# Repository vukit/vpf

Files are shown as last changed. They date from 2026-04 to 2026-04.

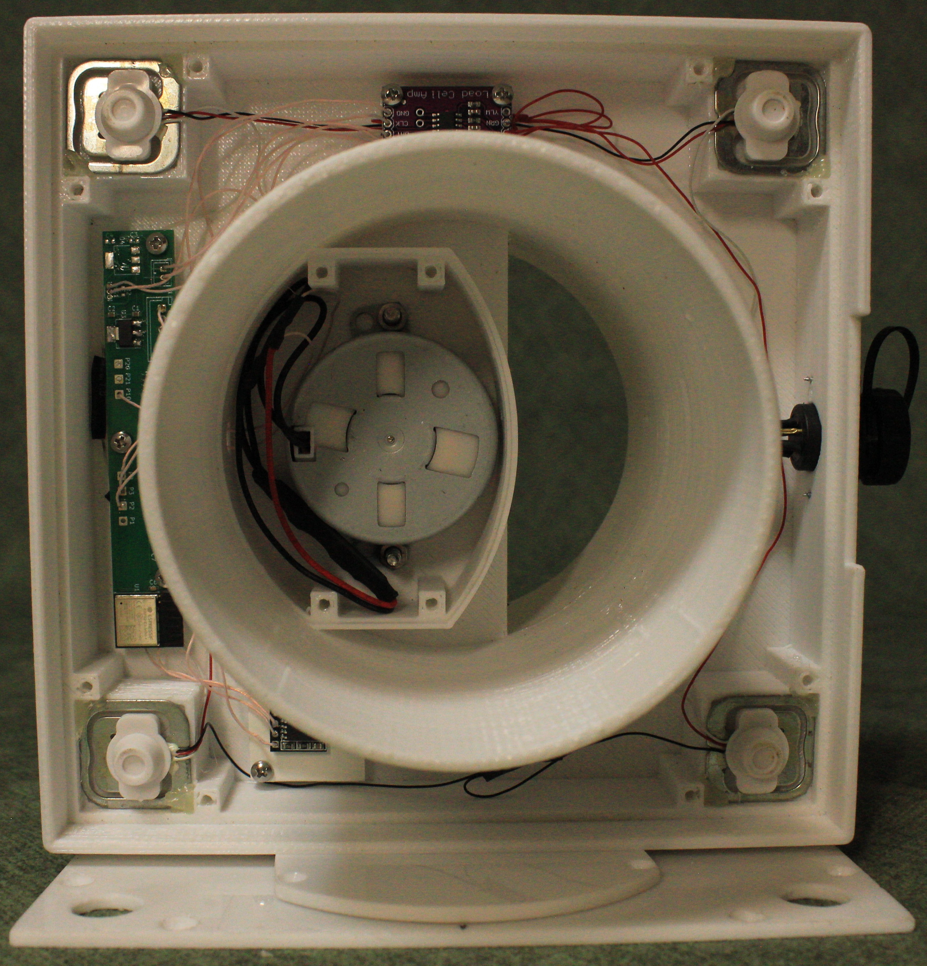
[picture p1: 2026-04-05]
photos/photo_1.jpg

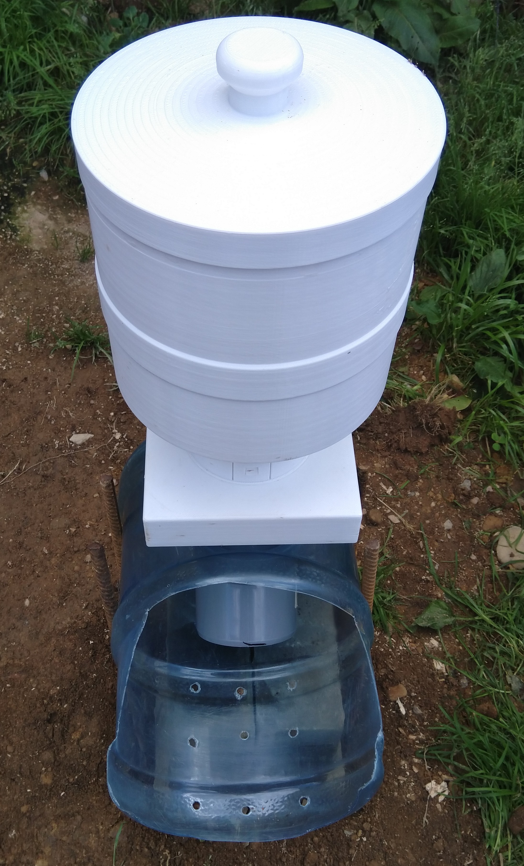
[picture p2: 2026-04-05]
photos/photo_2.jpg

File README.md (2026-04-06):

# Уличная кормушка для собак крупных пород

Надежная автоматизированная система кормления, спроектированная специально для крупных пород собак и эксплуатации в открытых вольерах. Проект успешно прошел проверку реальными условиями (снег, дождь, жара) и находится в эксплуатации с 2024 года.

## Ключевые особенности

*   **Компактный механизм:** Вместо громоздкого шнека использован оригинальный узел с пропеллером, что позволило существенно уменьшить габариты корпуса без потери производительности.
*   **Всепогодность:** Кормушка предназначена для установки на открытых площадках. Не требует навеса, дополнительной защиты или регулярной чистки механизма.
*   **Безопасность (5В):** Устройство питается от напряжения 5 вольт. Это гарантирует полную электрическую безопасность для питомца даже в случае повреждения кабеля.
*   **Автономность и объем:** Резервуар вмещает до 3.5 кг корма, чего достаточно для обеспечения собаки едой в течение 7 дней.
*   **Умная логика выдачи:** При временном отключении питания устройство автоматически «догоняет» график, выдавая пропущенные порции сразу после возобновления работы.

## Технические характеристики

*   **Точность дозирования:** ±20 грамм (порции задаются в граммах).
*   **График кормления:** До 3-х сессий в сутки в заданное время.
*   **Управление:** Мобильное приложение (связь через BLE).
*   **Функции приложения:** 
    *   Настройка расписания.
    *   Выдача порции вне очереди по команде.
    *   Обновление прошивки (OTA firmware update).

## Аппаратная часть
* **Микроконтроллер:** ESP32-C3.
* **Двигатель:** Bringsmart JS-50B(S) BLDC, DC 5V, CW/CCW, 2rpm, 10kgf/cm².
* **RTC:** Модуль DS3231 I2C.
* **Измерение веса:** TZT HX711 весовой модуль, 4 датчика FGHGF 34X34mm 5kg.
* **Питание:** 5В.

## Программное обеспечение
* **Язык:** firmware - C (ESP-IDF, FreeRTOS), приложение - Java (Android Studio).

## Опыт эксплуатации
Кормушка работает на открытом воздухе более 2-х лет, не требуя специального укрытия или частого технического обслуживания. Конструкция доказала свою устойчивость к обледенению и забиванию механизмов.

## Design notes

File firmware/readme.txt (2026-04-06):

Для успешной сборки проекта необходимо клонировать репозиторий https://github.com/UncleRus/esp-idf-lib.git в его корневую директорию

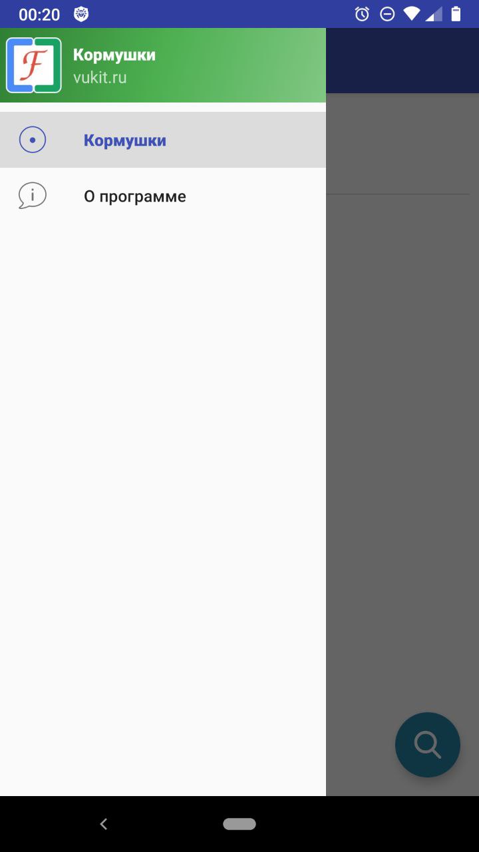
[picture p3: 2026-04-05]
screenshots/main_menu.jpg

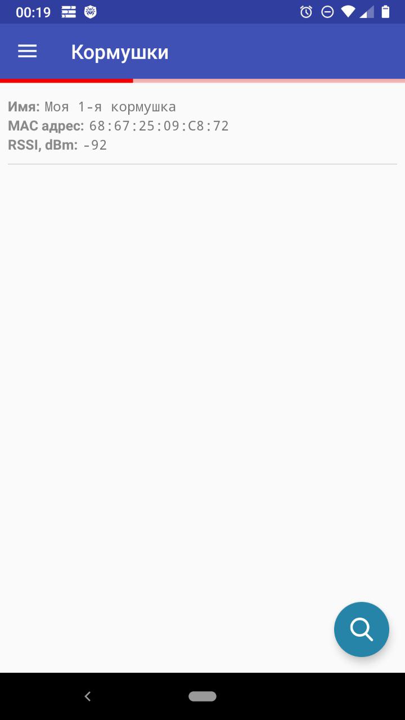
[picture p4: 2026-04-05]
screenshots/search_vpf.jpg

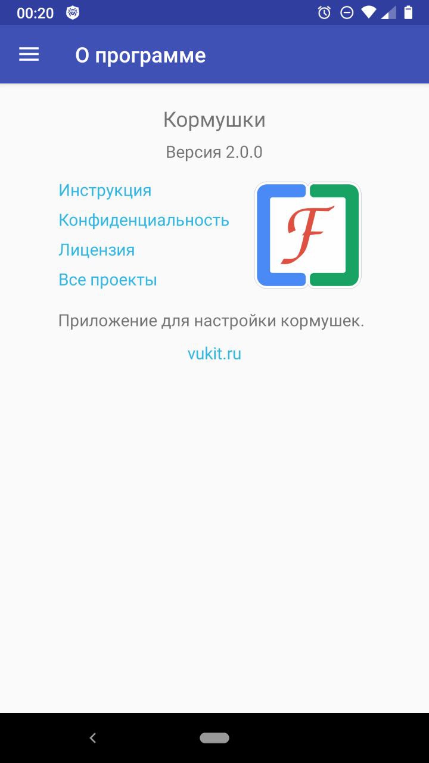
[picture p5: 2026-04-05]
screenshots/about.jpg

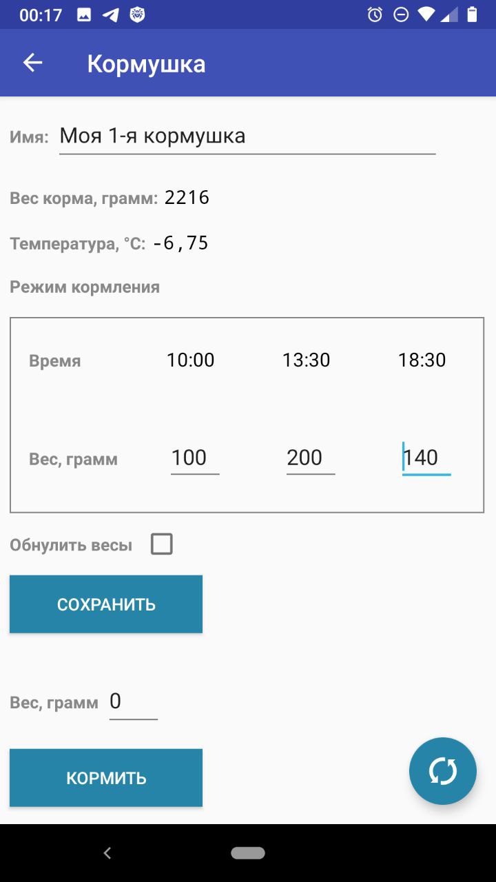
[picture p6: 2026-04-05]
screenshots/vpf_settings.jpg

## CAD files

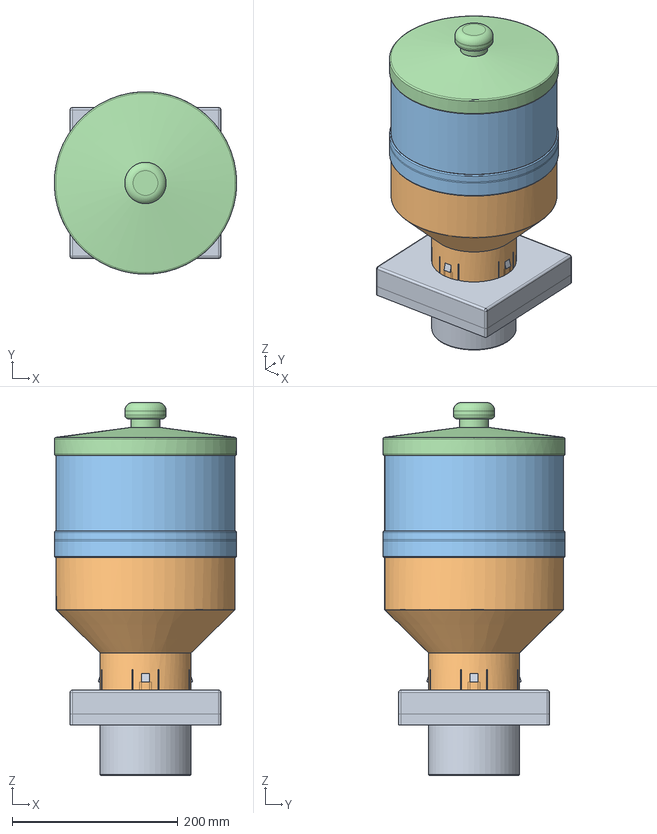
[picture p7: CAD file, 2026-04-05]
freecad/vpf_assembled.FCStd
220.0 x 219.9 x 450.0 mm
vpf_main_v2_001
vpf_tank_v2_001
vpf_ring_v2_001
vpf_cap_v2_001

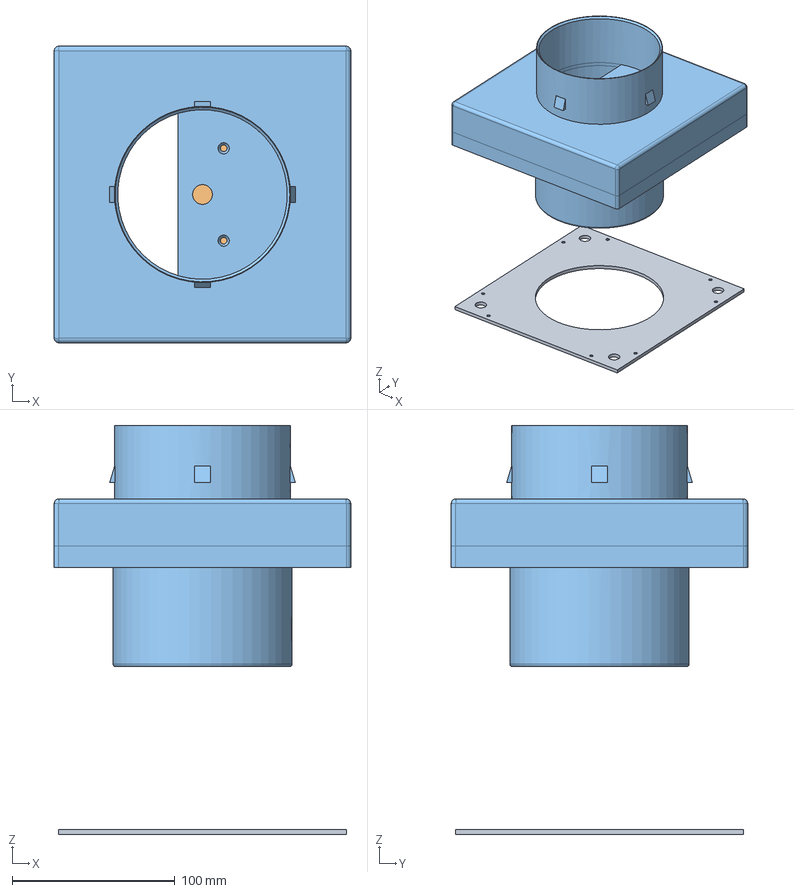
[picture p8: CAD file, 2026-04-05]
freecad/vpf_main.FCStd
182.0 x 182.0 x 251.0 mm
крышка
моторная_крышка
корпус

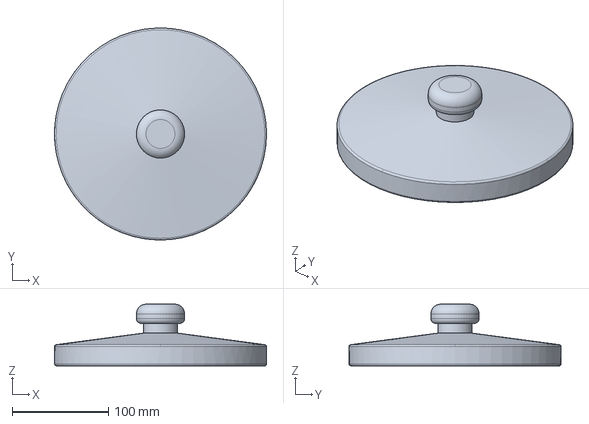
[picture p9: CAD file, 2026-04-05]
freecad/vpf_cap.FCStd
220.0 x 220.0 x 64.0 mm

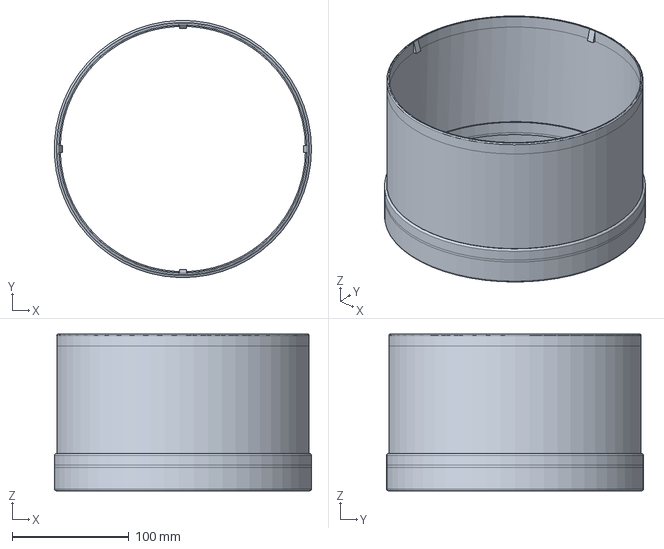
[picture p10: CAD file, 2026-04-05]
freecad/vpf_ring.FCStd
219.8 x 219.9 x 134.0 mm

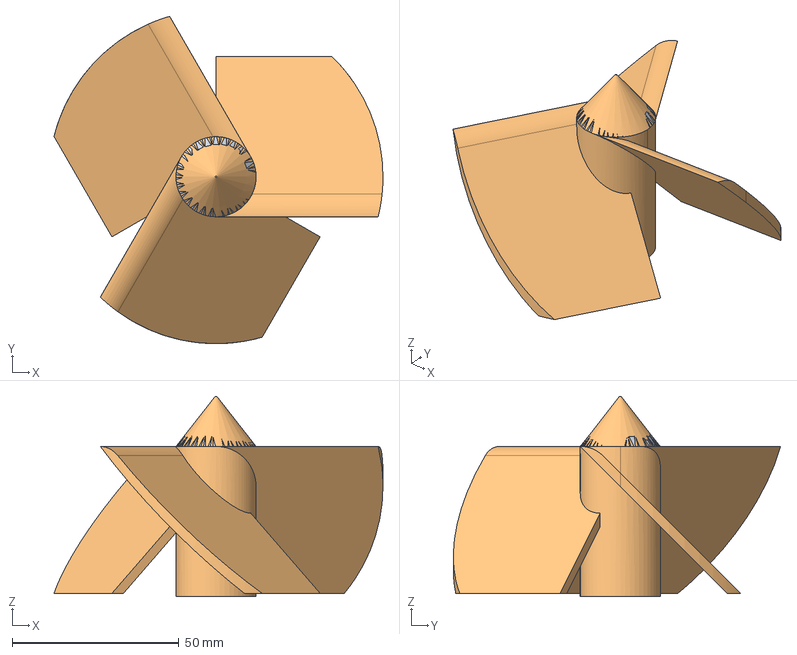
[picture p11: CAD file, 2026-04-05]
freecad/vpf_feeder.FCStd
98.5 x 98.0 x 60.0 mm
крышка
поддадчик

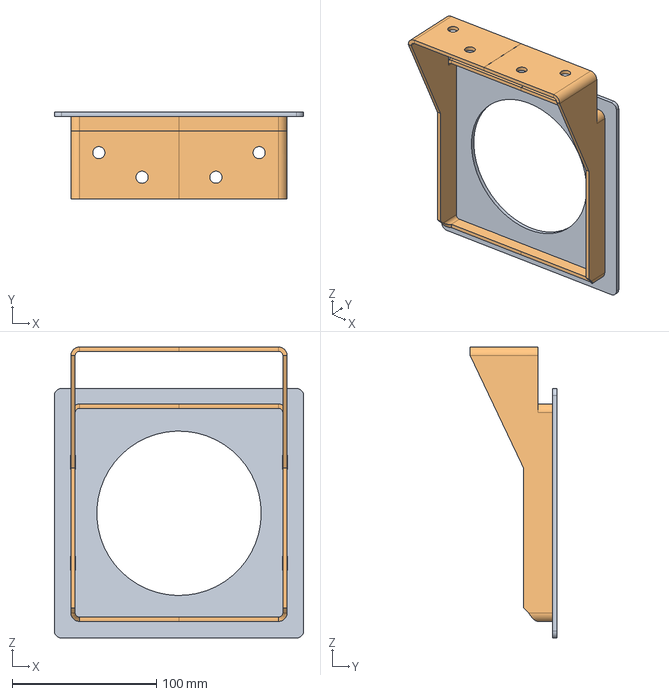
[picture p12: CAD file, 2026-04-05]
freecad/vpf_holder.FCStd
173.0 x 60.1 x 201.8 mm
верх
низ_развёртка

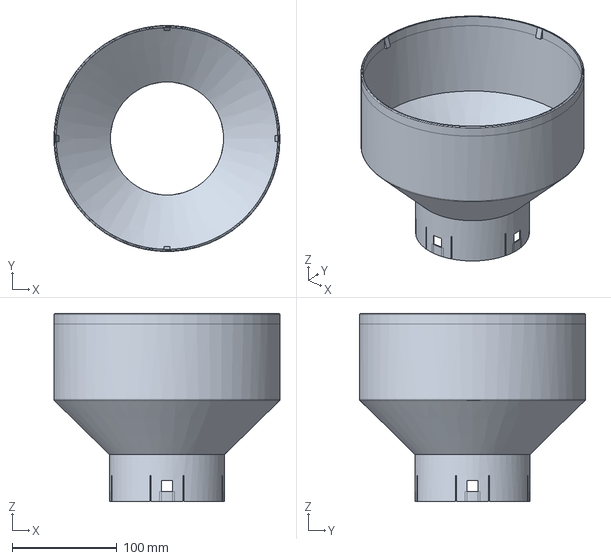
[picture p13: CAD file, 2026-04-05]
freecad/vpf_tank.FCStd
216.0 x 215.9 x 179.9 mm

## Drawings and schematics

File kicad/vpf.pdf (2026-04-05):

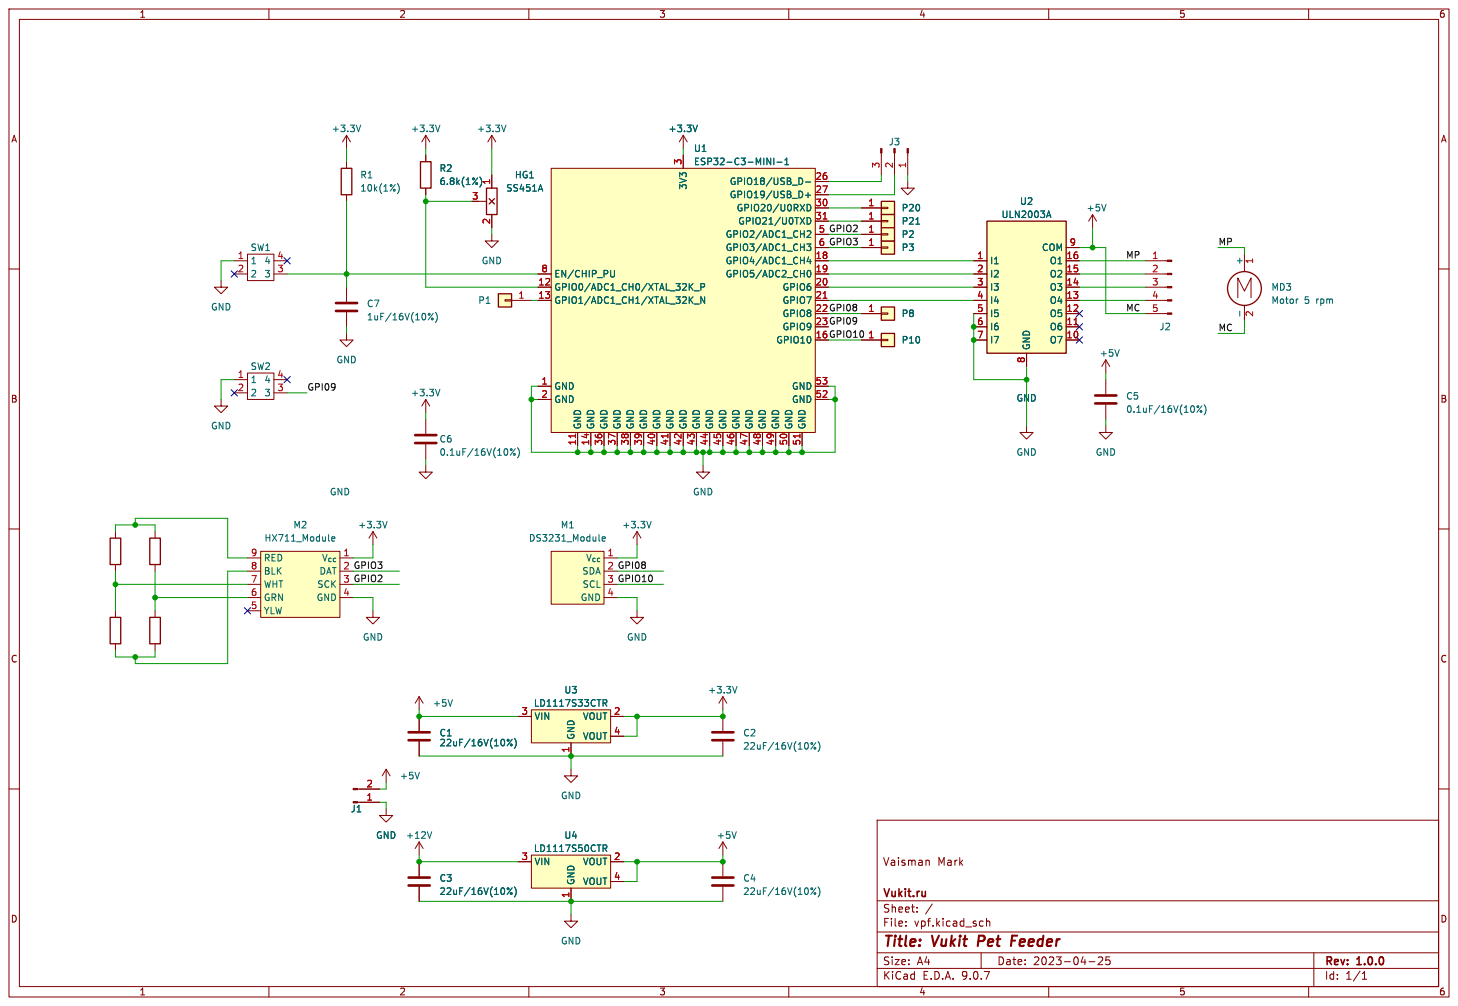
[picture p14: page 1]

3 GND 42 GND 43 GND 44 GND 45 GND 46 GND 47 GND 48 GND 49 GND 50 GND 51 GPIO18/USB_D- 26 GPIO19/USB_D+ 27 GPIO20/U0RXD 30 GPIO21/U0TXD 31 GPIO2/ADC1_CH2 5 GPIO3/ADC1_CH3 6 GPIO4/ADC1_CH4 18 GPIO5/ADC2_CH0 19 GPIO6 20 GPIO7 21 GPIO8 22 GPIO9 23 GPIO10 16 GND 53 GND 52 +3.3V

3 GND 42 GND 43 GND 44 GND 45 GND 46 GND 47 GND 48 GND 49 GND 50 GND 51 GPIO18/USB_D- 26 GPIO19/USB_D+ 27 GPIO20/U0RXD 30 GPIO21/U0TXD 31 GPIO2/ADC1_CH2 5 GPIO3/ADC1_CH3 6 GPIO4/ADC1_CH4 18 GPIO5/ADC2_CH0 19 GPIO6 20 GPIO7 21 GPIO8 22 GPIO9 23 GPIO10 16 GND 53 GND 52 U1ESP32-C3-MINI-1 GND MP MC GPIO2 GPIO3 GPIO2 MP GPIO10 GPI08 GPIO3 GPI09 GPI08 GPIO10 MC GPI09 U1ESP32-C3-MINI-1 EN/CHIP_PU 8 GPIO0/ADC1_CH0/XTAL_32K_P 12 GPIO1/ADC1_CH1/XTAL_32K_N 13 GND 1 GND 2 GND 11 GND 14 GND 36 GND 37 GND 38 GND 39 GND 40 GND 41 3V3

1 2 HG1 SS451A RED 9 BLK 8 WHT 7 GRN 6 YLW 5 V_{cc}1 DAT 2 SCK 3 GND 4 M2 HX711_Module

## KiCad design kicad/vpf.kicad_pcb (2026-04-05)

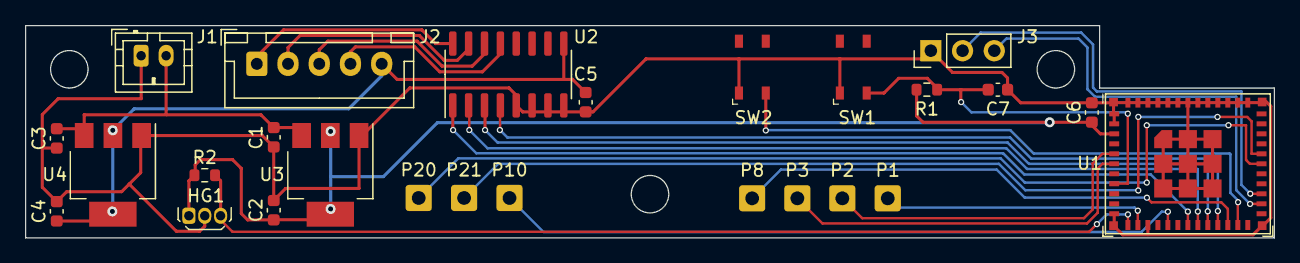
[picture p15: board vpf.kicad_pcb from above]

Board: 2 copper layers, 100.0 x 17.0 mm, 26 parts (0 on the bottom side), 24 nets.

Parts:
C1, C2, C3, C4: 22uF/16V(10%); C_0603_1608Metric
C5, C6: 0.1uF/16V(10%); C_0603_1608Metric
C7: 1uF/16V(10%); C_0603_1608Metric
HG1: SS451A; TO-92Flat
J1: Conn_01x02_Pin; JST_PH_B2B-PH-K_1x02_P2.00mm_Vertical
J2: Conn_01x05_Pin; JST_XH_B5B-XH-A_1x05_P2.50mm_Vertical
J3: Conn_01x03_Pin; PinHeader_1x03_P2.54mm_Vertical
P1, P2, P3, P8, P10, P20, P21: Conn_01x01; SolderWire-0.5sqmm_1x01_D0.9mm_OD2.1mm
R1: 10k(1%); R_0603_1608Metric
R2: 6.8k(1%); R_0603_1608Metric
SW1, SW2: PTS810SJM250SMTRLFS; SW_PUSH_4
U1: ESP32-C3-MINI-1
U2: ULN2003A; SOIC-16_3.9x9.9mm_P1.27mm
U3: LD1117S33CTR; SOT-223
U4: LD1117S50CTR; SOT-223

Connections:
+3.3V: C2.1, C6.1, HG1.1 (U1), R1.1, R2.1, U1.3 (3V3), U3.2 (VOUT), U3.4 (VOUT)
+5V: C4.1, C5.1, J2.5, U2.9 (COM), U4.2 (VOUT), U4.4 (VOUT)
+12V: C1.1, C3.1, J1.2, U3.3 (VIN), U4.3 (VIN)
/GPI09: SW2.3, U1.23 (GPIO9)
GND: C1.2, C2.2, C3.2, C4.2, C5.2, C6.2, C7.2, HG1.2 (U2), J1.1, J3.1, SW1.1, SW2.1, U1.1 (GND), U1.2 (GND), U1.11 (GND), U1.14 (GND), U1.36 (GND), U1.37 (GND), U1.38 (GND), U1.39 (GND), U1.40 (GND), U1.41 (GND), U1.42 (GND), U1.43 (GND), U1.44 (GND), U1.45 (GND), U1.46 (GND), U1.47 (GND), U1.48 (GND), U1.49 (GND), U1.50 (GND), U1.51 (GND), U1.52 (GND), U1.53 (GND), U2.5 (I5), U2.6 (I6), U2.7 (I7), U2.8 (GND), U3.1 (GND), U4.1 (GND)
unnamed: HG1.3 (UH1), R2.2, U1.12 (GPIO0/ADC1_CH0/XTAL_32K_P)
unnamed: J2.1, U2.16 (O1)
unnamed: J2.2, U2.15 (O2)
unnamed: J2.3, U2.14 (O3)
unnamed: J2.4, U2.13 (O4)
unnamed: J3.2, U1.27 (GPIO19/USB_D+)
unnamed: J3.3, U1.26 (GPIO18/USB_D-)
unnamed: P1.1, U1.13 (GPIO1/ADC1_CH1/XTAL_32K_N)
unnamed: P2.1, U1.5 (GPIO2/ADC1_CH2)
unnamed: P3.1, U1.6 (GPIO3/ADC1_CH3)
unnamed: P8.1, U1.22 (GPIO8)
unnamed: P10.1, U1.16 (GPIO10)
unnamed: P20.1, U1.30 (GPIO20/U0RXD)
unnamed: P21.1, U1.31 (GPIO21/U0TXD)
unnamed: C7.1, R1.2, SW1.3, U1.8 (EN/CHIP_PU)
unnamed: U1.18 (GPIO4/ADC1_CH4), U2.1 (I1)
unnamed: U1.19 (GPIO5/ADC2_CH0), U2.2 (I2)
unnamed: U1.20 (GPIO6), U2.3 (I3)
unnamed: U1.21 (GPIO7), U2.4 (I4)

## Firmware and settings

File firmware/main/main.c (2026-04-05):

#include "sdkconfig.h"
#include "freertos/FreeRTOS.h"
#include "nvs_flash.h"
#include "esp_log.h"
#include "esp_ota_ops.h"
#include "main.h"
#include "i2cdev.h"
#include "ble/server.h"
#include "motor/motor.h"
#include "state/state.h"
#include "scales/scales.h"
#include "clock/clock.h"
#include "command/command.h"
#include "worker/worker.h"

#define MAIN_LOG_TAG "MAIN"

bool run_diagnostics()
{
    // do some diagnostics
    return true;
}

void app_main(void)
{
    esp_err_t err;

    esp_reset_reason_t reason = esp_reset_reason();
    ESP_LOGI(MAIN_LOG_TAG, "Reset Reason : %X", reason);

    // check which partition is running
    const esp_partition_t *partition = esp_ota_get_running_partition();
    switch (partition->address)
    {
    case 0x00010000:
        ESP_LOGI(MAIN_LOG_TAG, "Running partition: factory");
        break;
    case 0x00110000:
        ESP_LOGI(MAIN_LOG_TAG, "Running partition: ota_0");
        break;
    case 0x00210000:
        ESP_LOGI(MAIN_LOG_TAG, "Running partition: ota_1");
        break;

    default:
        ESP_LOGE(MAIN_LOG_TAG, "Running partition: unknown");
        break;
    }

    // check if an OTA has been done, if so run diagnostics
    esp_ota_img_states_t ota_state;
    if (esp_ota_get_state_partition(partition, &ota_state) == ESP_OK)
    {
        if (ota_state == ESP_OTA_IMG_PENDING_VERIFY)
        {
            ESP_LOGI(MAIN_LOG_TAG, "An OTA update has been detected.");
            if (run_diagnostics())
            {
                ESP_LOGI(MAIN_LOG_TAG, "Diagnostics completed successfully! Continuing execution.");
                esp_ota_mark_app_valid_cancel_rollback();
            }
            else
            {
                ESP_LOGE(MAIN_LOG_TAG, "Diagnostics failed! Start rollback to the previous version.");
                esp_ota_mark_app_invalid_rollback_and_reboot();
            }
        }
    }

    // Initialize NVS
    err = nvs_flash_init();
    if (err == ESP_ERR_NVS_NO_FREE_PAGES || err == ESP_ERR_NVS_NEW_VERSION_FOUND)
    {
        ESP_ERROR_CHECK(nvs_flash_erase());
        err = nvs_flash_init();
    }
    ESP_ERROR_CHECK(err);

    // Initialize I2C
    err = i2cdev_init();
    if (err != ESP_OK)
    {
        ESP_LOGE(MAIN_LOG_TAG, "i2cdev_init(): %d (%s)\n", err, esp_err_to_name(err));
    }

    state_init();

    motor_init();

    scales_init();

    clock_init();

    ble_init();

    command_init();

    worker_run();
}

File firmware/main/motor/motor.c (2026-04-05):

#include <stdio.h>
#include "sdkconfig.h"
#include "freertos/FreeRTOS.h"
#include "driver/gpio.h"
#include "esp_log.h"
#include "motor.h"

#define MOTOR_LOG_TAG "MOTOR"

void motor_init()
{
    ESP_LOGI(MOTOR_LOG_TAG, "Motor initialization.");
    gpio_reset_pin(CONFIG_MOTOR_DRIVER_PORT);
    gpio_pulldown_en(CONFIG_MOTOR_DRIVER_PORT);
    gpio_set_direction(CONFIG_MOTOR_DRIVER_PORT, GPIO_MODE_OUTPUT);
    gpio_set_level(CONFIG_MOTOR_DRIVER_PORT, 0);
}

void motor_start()
{
    ESP_LOGI(MOTOR_LOG_TAG, "Motor start.");
    gpio_set_level(CONFIG_MOTOR_DRIVER_PORT, 1);
}

void motor_stop()
{
    ESP_LOGI(MOTOR_LOG_TAG, "Motor stop.");
    gpio_set_level(CONFIG_MOTOR_DRIVER_PORT, 0);
}
